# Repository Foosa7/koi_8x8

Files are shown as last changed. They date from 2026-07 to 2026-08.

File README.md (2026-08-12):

# Koi 8×8 — 64-channel current-source driver / readout

An open-hardware, low-cost controller for driving **TiN thermo-optic heaters on
photonic chips**: 64 independent precision current sources with per-channel
voltage readback, built from one controller board and eight hot-pluggable
8-channel analog boards.

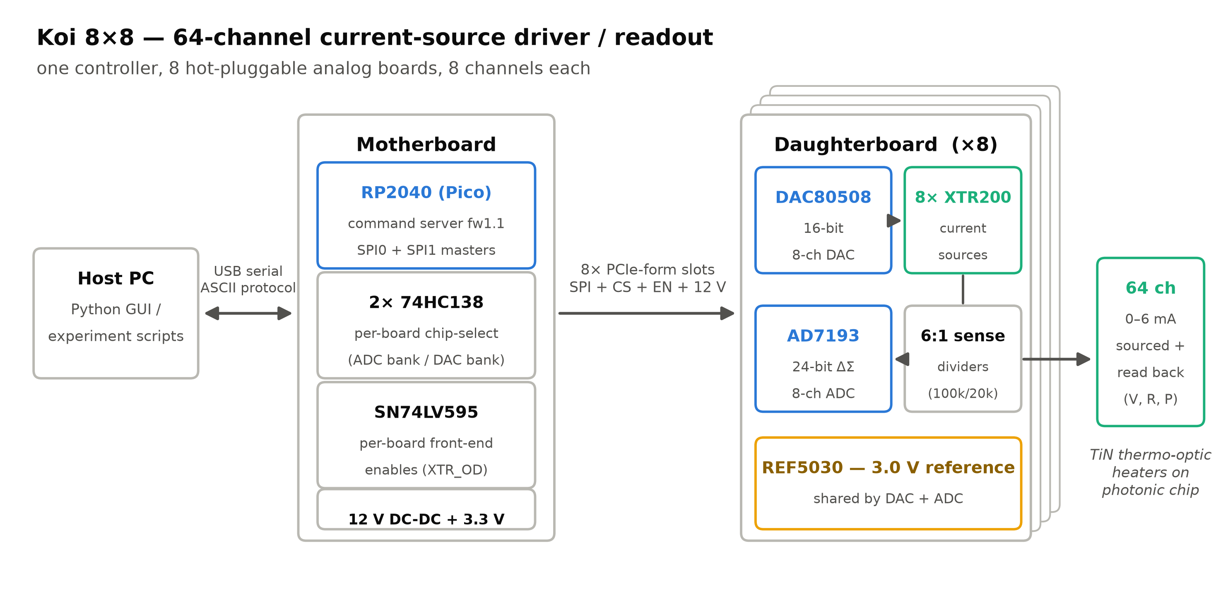
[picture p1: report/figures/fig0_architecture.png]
System architecture


Each daughterboard pairs a 16-bit DAC (DAC80508) with eight XTR200 precision
current sources, and reads the voltage across each load through a 6:1 divider
with a 24-bit ΔΣ ADC (AD7193), so the host gets current, voltage, resistance,
and power per channel. A Raspberry Pi Pico (RP2040) on the motherboard runs a
line-based ASCII command server over USB — one `ISETA` sets all 64 currents,
one `MEASA?` reads all 64 voltages.

## The boards

| [Motherboard](hardware/motherboard/) — RP2040 controller, 8 slots | [Daughterboard](hardware/daughterboard/) — 8 analog channels, ×8 |
| --- | --- |
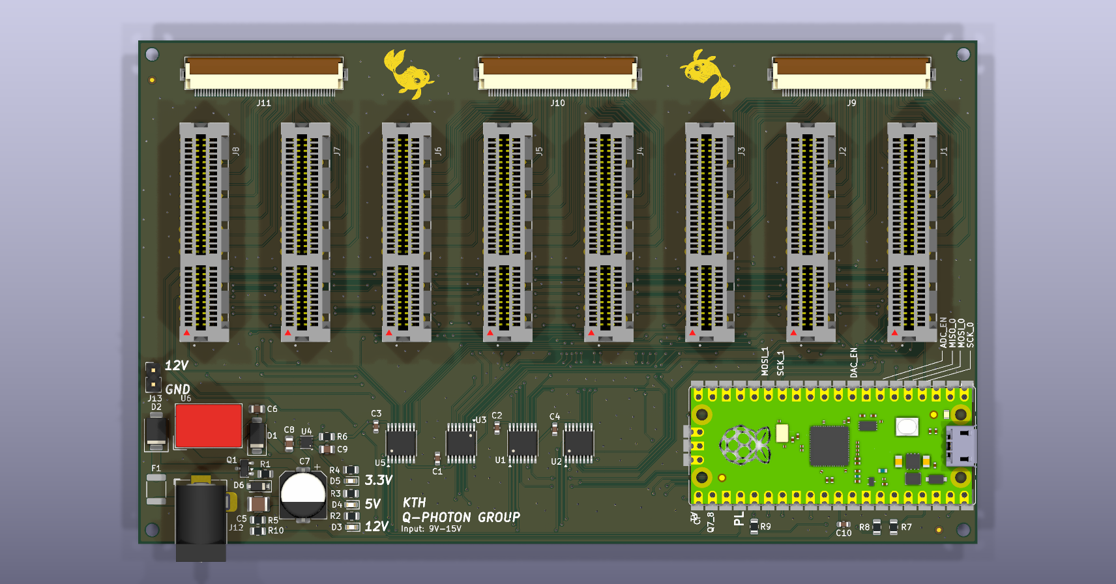
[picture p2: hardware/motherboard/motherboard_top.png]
Motherboard
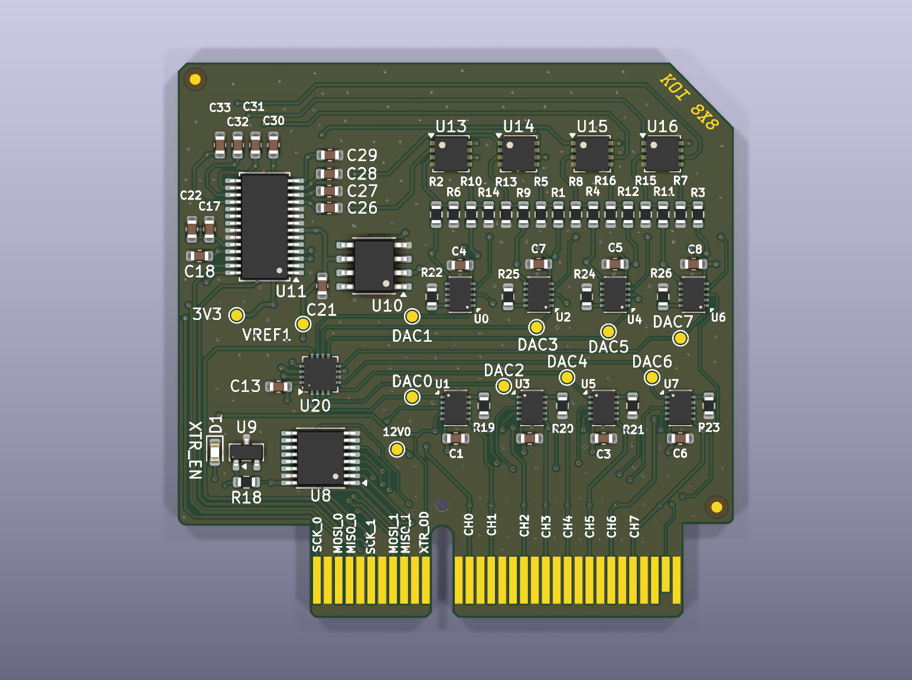
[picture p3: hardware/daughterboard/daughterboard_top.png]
Daughterboard
|  |  |

Renders are regenerated from the KiCad boards with `kicad-cli pcb render`; each
board's own README has top, bottom, and transparent-background views.

## Key numbers

| Metric | Value |
| --- | --- |
| Channels | 64 (8 boards × 8), hot-pluggable per board |
| Current range | 0–6 mA per channel (working range 0.25–6 mA), 16-bit setting |
| Readback | 24-bit ΔΣ, divider-corrected load voltage → V / R / P per channel |
| Linearity (measured, 23 ch) | worst-case ±0.32 µA deviation from linear over 0.25–6 mA (≈0.006 % of span) |
| Offset (pre-calibration) | ≈24 µA systematic, uniform across channels; single-point cal brings it to the ±4 µA XTR200 device floor (Keithley campaign planned) |
| Full 64-channel scan | ≈11 ms/channel at the default filter rate (~0.7 s for all 64; filter rate adjustable live) |
| Parts cost | **$709 per system ≈ $11.08/channel** ([master_bom.csv](master_bom.csv)) — commercial equivalents (e.g. Qontrol) ≈ $125/channel |

## Measured results (3 boards / 24 channels, 2026-07-03)

| | |
| --- | --- |
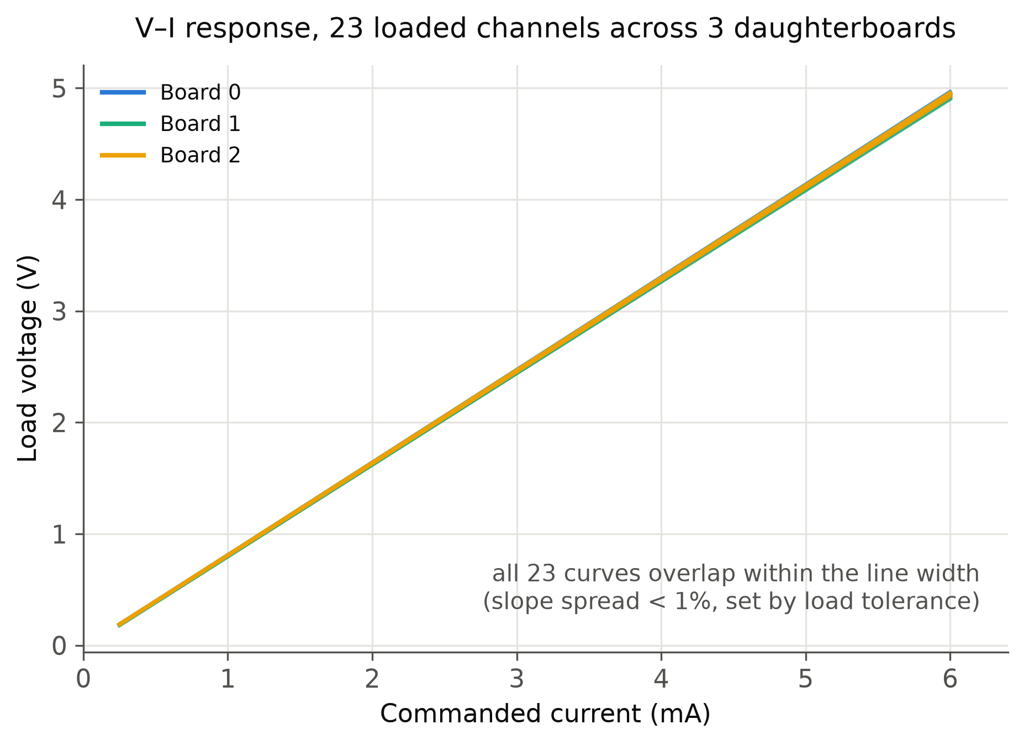
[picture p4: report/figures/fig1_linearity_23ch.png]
V-I linearity
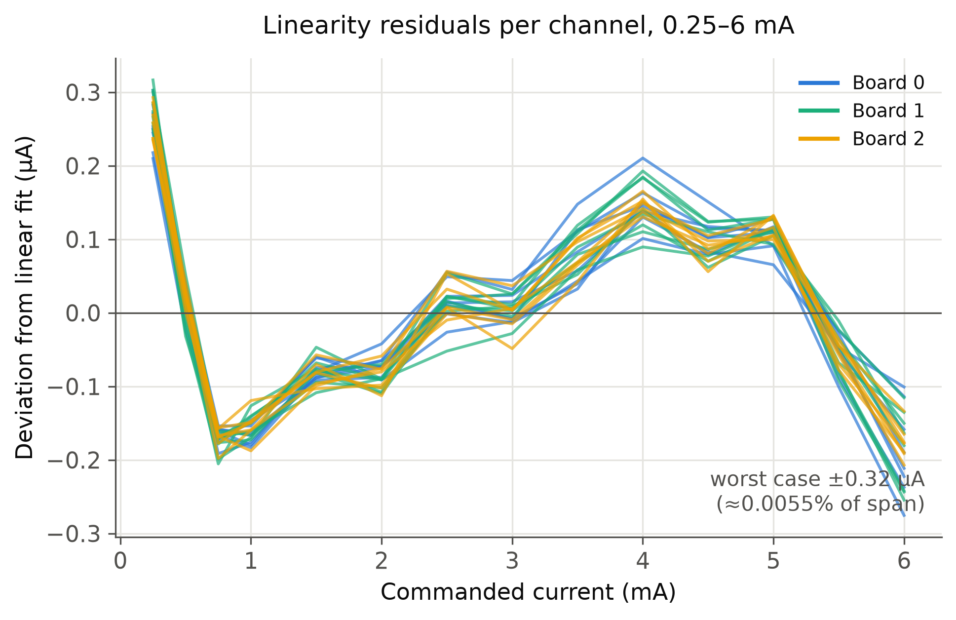
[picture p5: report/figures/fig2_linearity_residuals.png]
Residuals
|  |  |

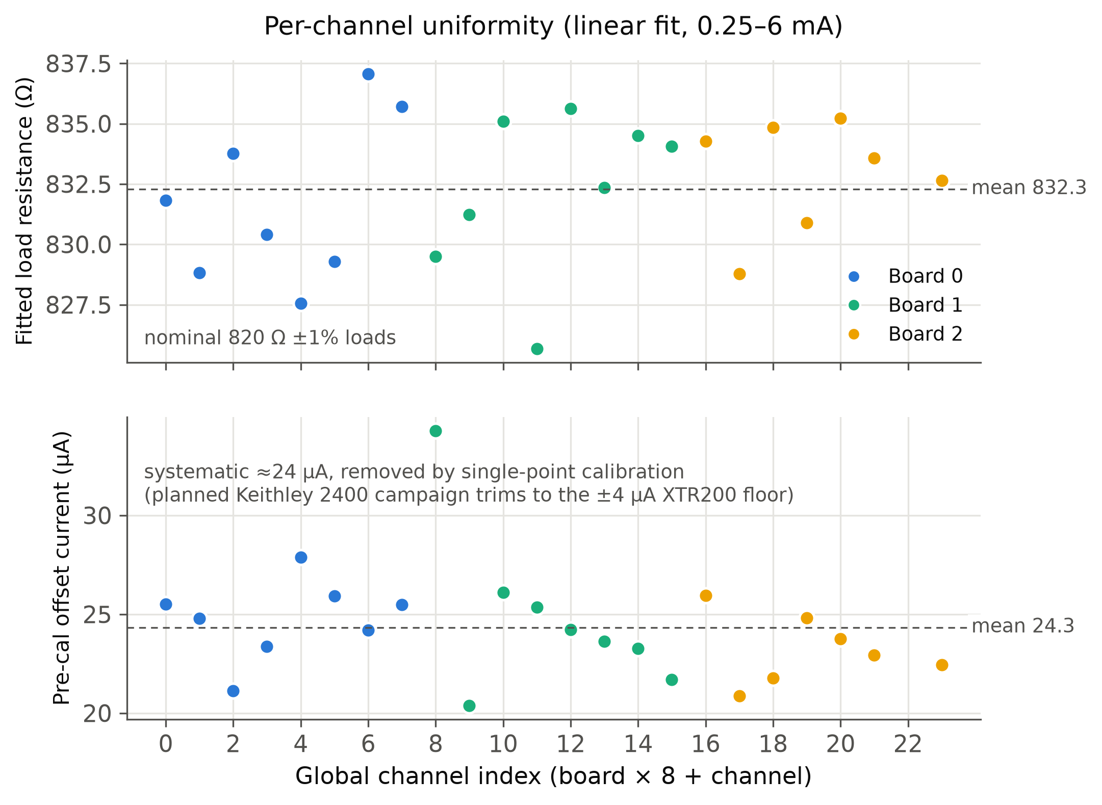
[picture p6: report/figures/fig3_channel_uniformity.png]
Per-channel uniformity


Three populated daughterboards were swept 0.1–6 mA into nominal 820 Ω ±1 %
loads (one channel had no load fitted during the run and is excluded). All 23
loaded channels are linear to within ±0.32 µA and show a uniform ~24 µA
pre-calibration offset — a systematic that the planned per-channel calibration
removes. Figures are regenerated from the raw bench CSVs by
`report/figures/make_figures.py`.

## What's in this folder

| Path | Contents |
| --- | --- |
| `report/figures/` | Architecture diagram + measurement figures (and the scripts that generate them) |
| `hardware/motherboard/` | KiCad project, schematic PDF (`Schematics/`), power-tree spec (`POWER.md`), top/bottom/transparent renders, fab outputs (`production/`: gerbers, BOM, positions) |
| `hardware/daughterboard/` | Same set for the analog board, plus an interactive HTML BOM (`bom/ibom.html`) |
| `hardware/render/` | Headless KiCad → pcb2blender → Cycles pipeline for photorealistic board renders |
| `master_bom.csv` | Consolidated system BOM with unit prices and cost total |
| `firmware/motherboard-test/` | RP2040 firmware (PlatformIO, `pio run -t upload`) and Python host tools — `tools/koi_gui.py` is a live 8×8 monitor GUI; `tools/*.csv` are the raw bench datasets |
| `paper/main.pdf` | Draft HardwareX manuscript (validation section pending the calibration campaign) |

## Status (August 2026)

**In fab:** both revised boards were released to fabrication on **2026-08-12**.
The motherboard adds the protected input stage (PPTC + SMBJ16A TVS + P-FET
reverse-polarity with a BZT52C18 gate clamp), the 12 → 5 → 3.3 V tree with the
`3V3_EN` interlock, a +12 V sense divider into `GPIO26`, and the `U3.~OE`
cutover to `GPIO19`; the daughterboard adds the OPA2333 followers (U13–U16) and
their 1 kΩ series resistors. `hardware/*/production/` holds the exact gerber /
BOM / position sets that were sent.

**Done:** rev-1 hardware designed, fabricated, and brought up; firmware 1.1
with robust host protocol (auto-detection, hot-rescan, fast scanning); host GUI
and calibration tooling; all 8 daughterboards populated and tested (initial
3-board/24-channel results above — production sign-off).

**Resolved:** the ~3 mV offset seen during the 8-board test was the AD7193's
*internal* input buffer. With the 6:1 divider, a low-current channel's ADC input
sits below the buffered mode's usable common-mode range, so the buffer added a
systematic offset rather than tracking. Fixed by disabling it (`CONF.BUF = 0`)
and adding 8 external unity-gain **OPA2333** followers (U13–U16) between the
divider taps and the ADC inputs.

**Next:** Keithley 2400/2100 per-channel calibration campaign (jig designed,
parts list ready); HardwareX submission.

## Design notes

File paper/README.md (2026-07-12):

# Koi 8×8 — HardwareX manuscript

Draft of the HardwareX paper for the 64-channel current-source driver / readout controller.

## Build
```bash
make            # -> main.pdf  (runs pdflatex twice)
make clean      # remove aux files
```
Requires `pdflatex` (TeX Live). No bibliography is wired up yet (`refs.bib` is empty).

## Status / how to work in it
- `main.tex` is the manuscript. It follows the HardwareX section order
  (Specifications table → Hardware in context → Description → Design files →
  BOM → Build → Operation → Validation → Capabilities → Declarations).
- Search `main.tex` for `\todo{...}` (rendered in red in the PDF) — each marks
  text or data still to add. The biggest block is **Section 8, Validation** —
  that's the Keithley calibration campaign output.
- Set `\draftfalse` (comment the `\drafttrue` line near the top) to hide the
  TODO/notes markers for a clean read-through.
- For final submission, port into the official HardwareX `els-cas-templates`
  (elsarticle) template; this article-class version is for drafting.

## Where the seeded content came from
Architecture prose, the host-command protocol table, the measurement model, and
preliminary bench numbers are transcribed from the project `CLAUDE.md`. The
calibration tables and all quantitative validation figures are pending the
Keithley 2400 campaign.

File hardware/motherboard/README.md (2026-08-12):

# Motherboard — RP2040 controller board

The controller board for Koi 8×8. Carries a Raspberry Pi Pico (RP2040) and
hosts up to 8 [daughterboards](../daughterboard/) in PCIe-x4 card-edge slots,
addressing each board's DAC/ADC over a shared SPI bus. Formerly codenamed
`MOBO`. The PC talks to the Pico's firmware over USB serial — see
[`firmware/motherboard-test/`](../../firmware/motherboard-test/).

| Top | Bottom |
| --- | --- |
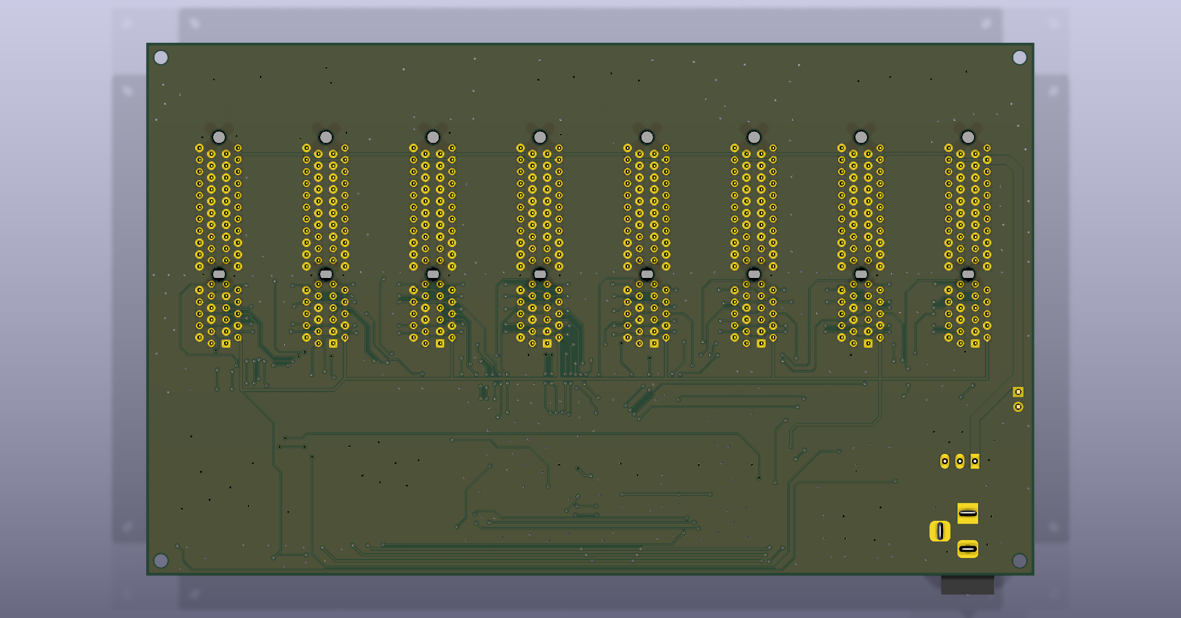
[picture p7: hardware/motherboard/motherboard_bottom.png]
Motherboard bottom
| Motherboard top |  |

Motherboard 3D render

Same top view with an alpha background, for dropping onto slides or into the
paper's figures:

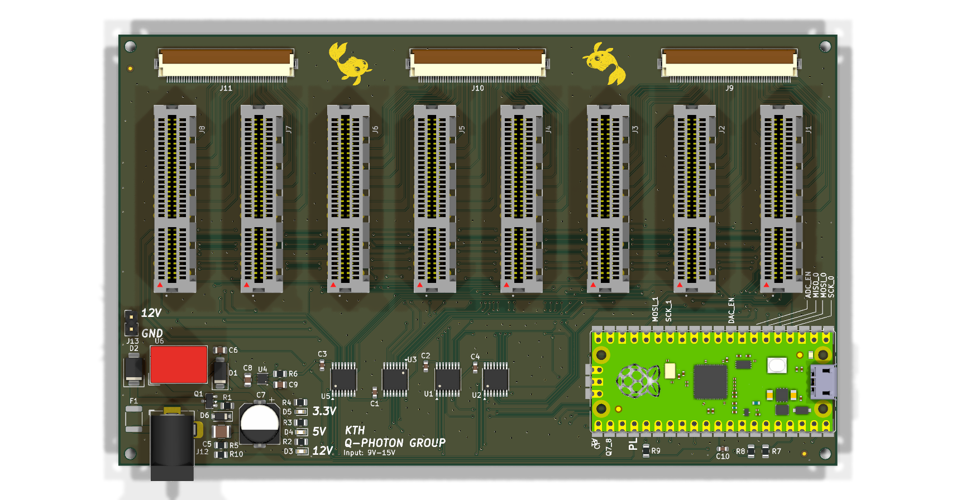
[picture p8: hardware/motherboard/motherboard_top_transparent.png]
Motherboard top, transparent background


## What's on it

| Ref | Part | Function |
| --- | --- | --- |
| A1 | Raspberry Pi Pico (RP2040) | Runs the firmware; USB-serial host link |
| U1, U5 | SN74LV138 (74HC138) | 3-to-8 decoders — ADC/DAC chip-select across the 8 slots |
| U3 | SN74LV595 | Shift register — XTR200 front-end enables |
| U2 | TMUX1208PW | 8:1 analog mux |
| J1–J8 | Samtec PCIE-064-02-F-D-TH | 8 daughterboard slots (PCIe-x4 sockets) |
| J9–J11 | Molex 54132-5033 | 50-pin FFC connectors — channel outputs |

### Power tree

The barrel jack is the only power source; the Pico is a peripheral that cannot
run without it, enforced in hardware by the `3V3_EN` interlock (R7/R8) rather
than in firmware. Full design rationale: [`POWER.md`](POWER.md).

| Ref | Part | Function |
| --- | --- | --- |
| J12 | Barrel jack + switch pin | DC power in, 9–15 V |
| F1 | 1812L150/24MR polyfuse | Input overcurrent protection |
| D2 | SMBJ16A | Input TVS clamp (26 V clamping voltage) |
| Q1 | AO3407A | P-FET reverse-polarity protection |
| D6 | BZT52C18 | `Q1` gate–source clamp |
| U6 | K7805-500R3 | 5 V switching regulator |
| U4 | LP5912-3.3DRV | 3.3 V LDO — logic rail and daughterboard `+3V3` |
| D1 | SS34 | Feeds the Pico's VSYS from the board's 5 V rail |
| R7, R8 | 10 kΩ / 4.7 kΩ | `3V3_EN` interlock divider |
| R5, R10, C10 | 100 kΩ / 22 kΩ / 100 nF | +12 V sense divider into `GPIO26`/ADC0 (×5.5455) |

Full pricing and part numbers: [`../../master_bom.csv`](../../master_bom.csv).

## Files

| File | What it is |
| --- | --- |
| `motherboard.kicad_pro` / `.kicad_sch` / `.kicad_pcb` | The KiCad project |
| `Schematics/motherboard.pdf` | Exported schematic |
| `production/` | Fab outputs — gerbers, BOM, positions, netlist |
| `POWER.md` | Power-tree design spec — input protection chain and the `3V3_EN` interlock |
| `motherboard*.png` | Board views above, regenerated with `kicad-cli pcb render` |
| `PCIE-064-02-F-D-TH.stp`, `Pico.wrl` | 3D models used for the renders above |

Photorealistic Cycles renders (`motherboard_render*.png`) are produced by the
pipeline in [`../render/`](../render/) — not generated yet.

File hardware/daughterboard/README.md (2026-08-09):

# Daughterboard — 8-channel analog board

The analog front-end board for Koi 8×8. Eight of these plug into one
[motherboard](../motherboard/) over a PCIe-x4 card-edge connector, giving the
system 8 boards × 8 channels = 64 independent current sources with voltage
readback. Formerly codenamed `OuttaQontrol`/`OuttaControl`.

| Top | Bottom |
| --- | --- |
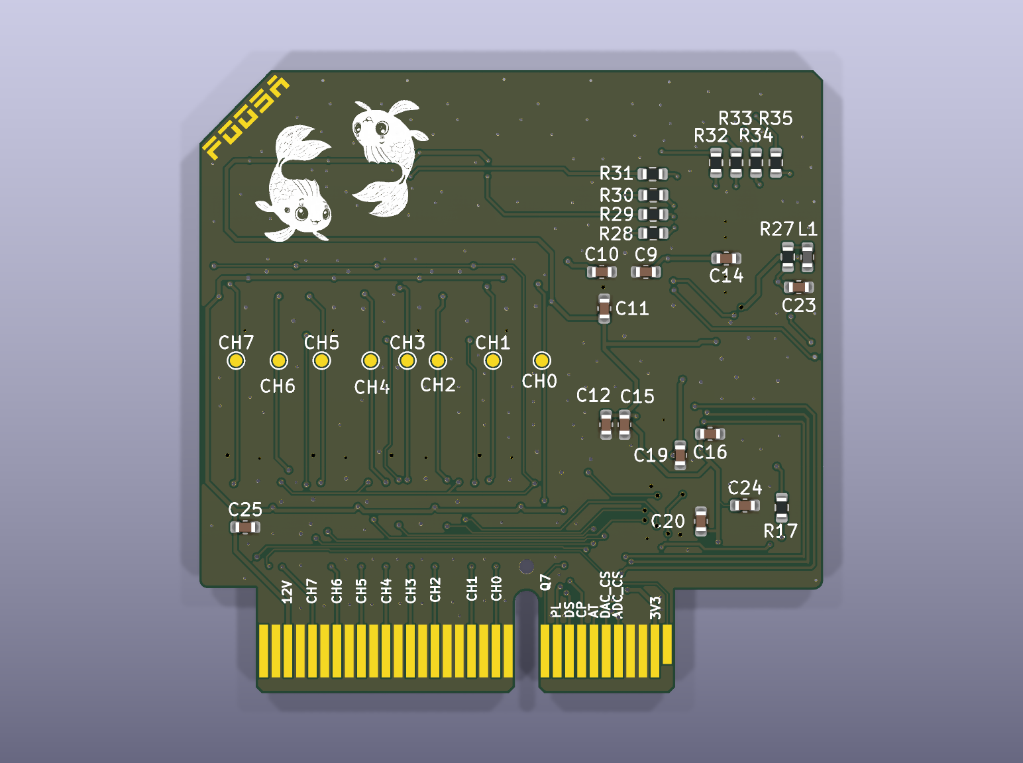
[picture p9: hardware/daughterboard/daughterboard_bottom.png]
Daughterboard bottom
| Daughterboard top |  |

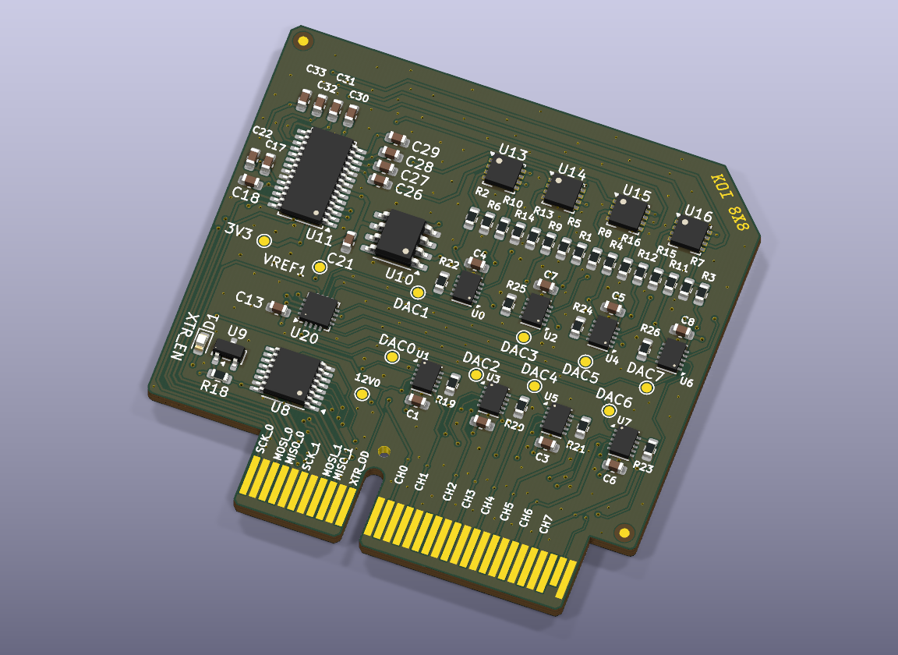
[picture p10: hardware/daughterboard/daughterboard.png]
Daughterboard 3D render


Same top view with an alpha background, for dropping onto slides or into the
paper's figures:

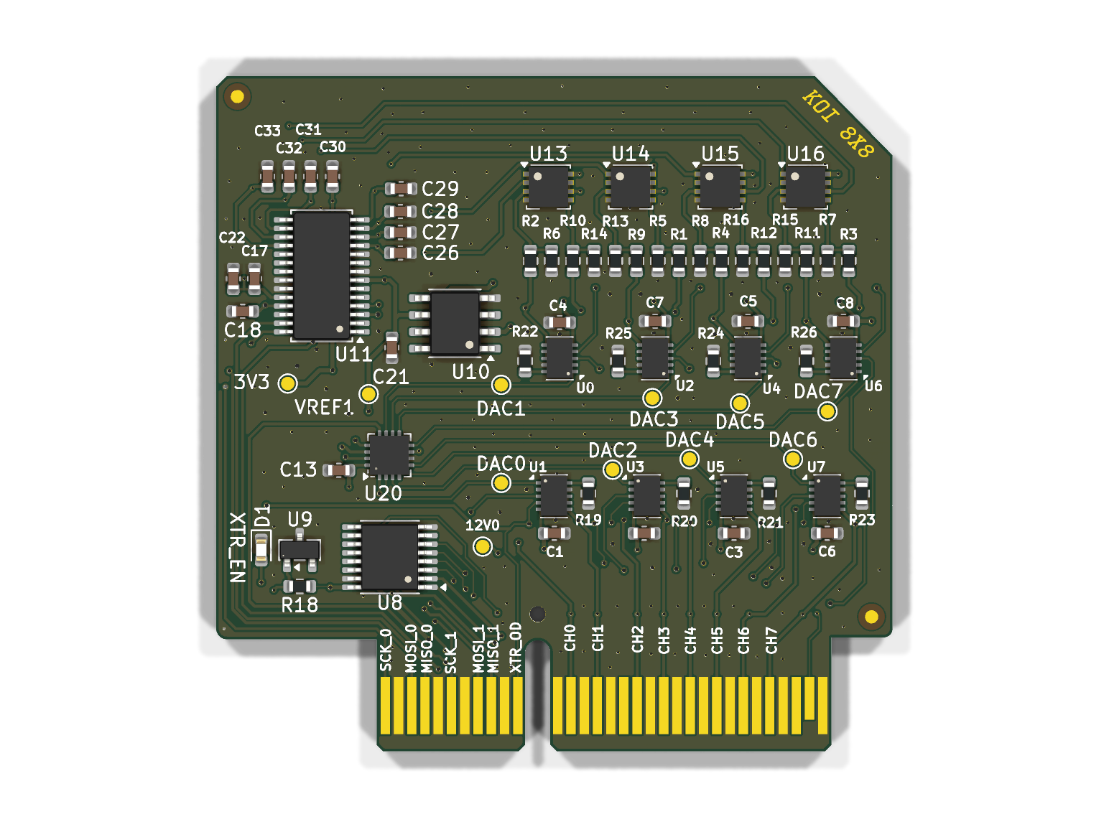
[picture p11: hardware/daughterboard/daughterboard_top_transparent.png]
Daughterboard top, transparent background


## What's on it

| Ref | Part | Function |
| --- | --- | --- |
| U0–U7 | XTR200 (WSON-10) | Precision current-source front end, one per channel |
| U20 | DAC80508Z (WQFN-16) | 16-bit, 8-channel DAC — sets the 8 channel currents |
| U11 | AD7193 (TSSOP-28) | 24-bit ΔΣ ADC — reads back the 8 channel voltages |
| U10 | REF5030 (SOIC-8) | 3.0 V precision reference, shared by the DAC and ADC on this board |
| U8 | SN74LV165A (TSSOP-16) | Parallel-load 8-bit shift register |
| U9 | AT21CS01 | 1-Wire EEPROM (board ID/config) — new in this revision |
| R19–R26 | 4.7 kΩ 0.1 % | Per-channel sense resistors |
| R1–R4, R9–R12, R17 / R5–R8, R13–R16 | 100 kΩ / 20 kΩ 0.1 % | 6:1 sense divider (top/bottom) — firmware reads the raw ADC-pin voltage and the host applies ×6 to get true heater voltage |
| J1 | Custom PCIe-x4 card-edge | Connector into the motherboard slot |

Full pricing and part numbers: [`../../master_bom.csv`](../../master_bom.csv).

## Files

| File | What it is |
| --- | --- |
| `daughterboard.kicad_pro` / `.kicad_sch` / `.kicad_pcb` | The KiCad project (current revision) |
| `Schematics/daughterboard.pdf` | Exported schematic |
| `bom/ibom.html` | Interactive HTML BOM (open in a browser) |
| `production/` | Fab outputs — gerbers, BOM, positions, netlist |
| `daughterboard*.png` | Board views above, regenerated with `kicad-cli pcb render` |
| `version 1/` | The prior board revision (pre-EEPROM), kept for reference, incl. its own PDN sim results |
| `padne_out_v3/`, `results_v3/` | Power-delivery-network (PDN) simulation outputs for this revision — current-density and IR-drop maps |

Photorealistic Cycles renders (`daughterboard_render*.png`) are produced by the
pipeline in [`../render/`](../render/) — not generated yet.

See **[`CLAUDE.md`](CLAUDE.md)** for the full development-facing breakdown of
these files, the netlist/revision history, and the padne PDN simulation
workflow in detail.

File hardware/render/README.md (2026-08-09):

# Photorealistic board renders

Cycles renders of the two KiCad boards, via
[pcb2blender](https://github.com/30350n/pcb2blender) (GPL-3.0, by 30350n). The
`.pcb3d` intermediate carries the real soldermask/silkscreen/copper artwork as
texture maps plus the component meshes, so the output is a lit 3D scene rather
than KiCad's viewport screenshot.

These are **separate files** from the `kicad-cli`-generated `*_top.png` /
`*_bottom.png` / `*.png` next to each project — those stay as the quick
reference views. Blender output is named `*_render*.png`.

## One-time setup

The upstream release is pinned to KiCad 9.0 / Blender 5.1; both need nudging.

1. **Blender add-on.** Download `pcb2blender_importer_v2-17-5_b5-1.zip` from the
   [v2.17.5 release](https://github.com/30350n/pcb2blender/releases/tag/v2.17.5-k9.0-b5.1).
   Blender 5.2 is excluded by the manifest's `blender_version_max`, so raise it
   before installing:

   ```bash
   unzip -q pcb2blender_importer_v2-17-5_b5-1.zip -d imp && \
   sed -i 's/^blender_version_max = "5.2.0"/blender_version_max = "5.3.0"/' imp/blender_manifest.toml && \
   (cd imp && zip -qr ../importer_patched.zip .) && \
   blender --command extension install-file -r user_default --enable importer_patched.zip
   ```

2. **Exporter.** Already vendored here as `pcb2blender_exporter/` (`export.py` +
   `pcb3d.py`, unmodified, from `pcb2blender_exporter_v2-17-5_k9-0.zip`). It is
   normally a pcbnew action plugin; `export_pcb3d.py` drives it headless instead.

## Running

```bash
./hardware/render/render.sh              # both boards, all four views
./hardware/render/render.sh mother       # one board
SAMPLES=320 ./hardware/render/render.sh  # slower, cleaner
```

Roughly 8 min per view at 1568×1176 / 160 samples on 12 CPU cores.

## Files

| File | What it does |
| --- | --- |
| `export_pcb3d.py` | `.kicad_pcb` → `.pcb3d`, headless. Patches `pcbnew.GetBoard()` and routes VRML export through `kicad-cli`. |
| `render_pcb.py` | Blender script: import `.pcb3d`, build a studio rig, render. `--view iso\|top\|bottom`, `--transparent`, `--samples`, `--exposure`. |
| `render.sh` | Both boards × four views at the sizes the READMEs expect. |
| `pcb2blender_exporter/` | Vendored upstream exporter (GPL-3.0). |

## KiCad 10 notes

- `pcbnew.ExportVRML()` returns `False` outside the pcbnew GUI, so
  `export_pcb3d.py` shells out to `kicad-cli pcb export vrml` instead. That call
  **must** pass `--user-origin 0x0mm`: the plugin emits pad coordinates in
  absolute page mm, and kicad-cli otherwise centres the mesh on its own origin,
  scattering every solder joint ~100 mm off the board.
- `unknown drill shape '2'` during export is harmless — KiCad 10 added
  `PAD_DRILL_SHAPE_UNDEFINED`, which the pinned exporter's enum doesn't list. It
  degrades to `UNKNOWN` and only affects solder-joint geometry on pads with no
  drill.
- Cycles' device enumeration walks *every* GPU backend, and the oneAPI
  level-zero loader segfaults Blender on this machine, so renders default to
  CPU. `--gpu` opts back in if that gets fixed.

## Surface finish

Both boards carry `copper_finish "None"` in their KiCad stackup, which would
render the PCIe edge fingers as bare copper. `render.sh` passes `--finish ENIG`
to override that. Fix the stackup in KiCad and the override can go.

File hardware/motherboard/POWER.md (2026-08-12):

# Motherboard power tree — design spec

Protected barrel-jack entry, 5 V buck, 3.3 V LDO, and a hardware interlock that makes the Pico a
subsystem of the board rather than an independent peer.

**Status: released to fabrication 2026-08-12.** The tree, the protection chain and the interlock
are on the board as of `397a4a4`; "What exists today" lists what is still outstanding. Input range
for this revision is **9–15 V**. Changes are no longer free — this revision is at the fab, so
anything below now describes a future spin.

Make changes **in KiCad**, not by editing `motherboard.kicad_sch` by hand.

## Architectural rule

**The barrel jack is the only power source, and the Pico cannot run without it.**

The Pico is a communications peripheral. It never sources power into the board, the board never
back-powers it, and — the part that makes everything else simple — the two can never be in
different power states. That last property is enforced in hardware by the `3V3_EN` interlock
below, not in firmware.

## What exists today

**Built as of `397a4a4` (2026-08-10).** The rework in this document has landed: the protection
chain, the two-stage tree and the interlock are all in the schematic and on the board. All three
defects this section used to list are fixed.

```
J12 ──► VIN_JACK ──► F1 (1812L150/24MR) ──┬──► D2 (TVS) ──► GND
                                          └──► Q1 (AO3407A) drain
                            Q1 source ──► +12V ──┬──► J1–J8 pin A30, J13
                                                 ├──► C5 10µ, C7 220µ/35 V
                                                 └──► U6 (K7805-500R3) Vin
                                 U6 Vout ──► +5V ──┬──► D1 (SS34) ──► VSYS (A1 pin 39)
                                                   ├──► U4 (LP5912-3.3) IN + EN
                                                   └──► C6 22µ, C8 10µ
                                 U4 OUT ──► +3.3V ──► U1/U2/U3/U5, J1–J8 pin A2, C1–C4 100n, C9 10µ
                                 U4 PG  ──► R6 100k ──► +3.3V, and A1 pin 11 (GPIO8)
      3V3_EN (A1 pin 37) ──┬── R7 10k ── GND
                           └── R8 4.7k ── +3.3V (U4 pin 1)
      +12V ──► R5 100k ──┬── 12V_SENSE ──► A1 pin 31 (GPIO26/ADC0)
                         ├── R10 22k ── GND
                         └── C10 100n ── GND (at the Pico pin)
      A1 pin 36 (3V3) and pin 40 (VBUS): unconnected.
      R1 100k: Q1 gate → GND.   D6: Q1 gate–source clamp.   R9 10k: U3 `~OE` pull-up.
      D3/D4/D5 + R2/R3/R4: rail LEDs on +12 V / +5 V / +3.3 V.
```

**Input range for this revision is 9–15 V**, set at the jack. This is wider than the 12 V nominal
the first draft assumed, and it drives the D2 and D6 selections below. Note the jack voltage *is*
the +12 V rail — it reaches `J1..J8.A30` and thence `VSP` (pin 5) of all 64 XTR200s — so it is not
a free input range: raising it raises XTR200 pass dissipation proportionally.

### Refdes drift — read this before cross-referencing

The build tables further down were written against the pre-rework schematic and use refdes that
the board assigns differently. Current mapping:

| This document originally said | On the board | Role |
| --- | --- | --- |
| `U8` | **`U6`** | K7805-500R3 buck |
| `R3` | **`R1`** | Q1 gate → GND, 100 kΩ |
| `D3` (optional gate zener) | **`D6`** | Q1 gate–source clamp — now placed, and now required |
| `C8` | **`C5`** | K7805 input, 10 µF 1210 |
| `C9` | **`C6`** | K7805 output, 22 µF 0805 |
| `C10` | **`C8`** | LDO input, 10 µF 0805 |
| `C11` | **`C9`** | LDO output, 10 µF 0805 |

`R2`/`R3`/`R4` and `D3`/`D4`/`D5` are the **rail LEDs** on the board, so the "Still to add" table's
use of `R4`, `R5` and `D4` for the sense divider and clamp is a collision.

`R5`, `R10` and `C10` are now the sense divider and its filter — note the bottom leg is **`R10`**,
not the `R13` earlier drafts of this document specced. Free refdes are `R11`+, `C11`+, `D7`+.

### Still outstanding

Verified against a fresh netlist export and the `.kicad_pcb` on **2026-08-11**. Schematic and
PCB agree on every net; no pad is left unreached by its own net's copper.

| Item | Where |
| --- | --- |
| `Q1` is drawn with the `AO3401A` symbol while valued `AO3407A` | "Schematic hygiene" |
| `D2`'s symbol carries no polarity (pins `A1`/`A2`) | "Schematic hygiene" |

**Electrically the board is complete.** Both open items are drawing hygiene, not connectivity.

Closed since the last revision of this document: the +12 V sense divider (`R5`/`R10`/`C10` →
`GPIO26`), the `U3.~OE` cutover to `GPIO19`, `D2` → `SMBJ16A`, `D6` → `BZT52C18`, the
`#PWR050`/`#PWR036` symbol swap, and `J1..J8.B31` → GND on all eight with the dangling one-node
`PRSNT` net deleted.

Decided against, deliberately — see "Board-side defaults" and "Decoupling": the `ADC_EN`/`DAC_EN`
pull-ups, the `U2` `EN` pull-down, and the 10 µF at the +3.3 V connector bank.

✅ **`production/` was regenerated 2026-08-11 20:27** from the current board — it now includes the
sense divider, the `~OE` cutover, the `D2`/`D6` changes and `J8.B31`. **This is the revision sent
to fabrication (2026-08-12).**

⚠️ **`motherboard.net` is still the 2026-08-10 18:04 export** and predates those changes. Re-export
from KiCad before using it to check connectivity; `production/netlist.ipc` is the current one.

✅ **DRC run 2026-08-12** (`kicad-cli pcb drc motherboard.kicad_pcb` — the CLI *can* open this board
now that KiCad 10.0.5 has re-saved it; only older on-disk formats defeated it). **0 errors, 0
unconnected pads**, 4 warnings, none of them manufacturing defects:

| Warning | What it is |
| --- | --- |
| `silk_overlap` ×1 | `CP` text vs `A1`'s reference designator |
| `silk_edge_clearance` ×2 | `J12` silkscreen clipped by the board edge |
| `lib_footprint_mismatch` ×1 | `U3`'s TSSOP-16 differs from `Package_SO`'s copy (local override) |

## Why this topology

The 5 V rail pre-regulates for the LDO and feeds VSYS. Dropping 12 V → 3.3 V linearly would
burn 8.7 V × 110 mA ≈ **0.96 W**; the switching stage cuts that to ~0.19 W. Switcher-then-LDO
also keeps switching noise off the rail feeding AD7193 AVDD.

The board previously carried an L7805 here, which threw that saving away: 7 V × 210 mA ≈ **1.5 W**
in TO-220F with no heatsink (θJA ≈ 60 °C/W) is a ~90 °C rise. The K7805-500R3's pinout is
deliberately LM78xx-compatible, so the swap cost **no net changes** — symbol, value and footprint
only. At 15 V in the linear option would have been worse still (9.7 V × 210 mA ≈ 2.0 W).

## The 3V3_EN interlock

`3V3_EN` is the RT6150's enable, pulled up to VSYS through 100 kΩ on the Pico module. Two
resistors turn "the Pico must not run without board power" into a hardware fact:

| Ref | Value | Connection |
| --- | --- | --- |
| `R7` | **10 kΩ** | 3V3_EN → GND |
| `R8` | **4.7 kΩ** | board +3.3 V (U4 pin 1) → 3V3_EN |

✅ **Built and verified against the netlist.** Both resistors carry these values and `R8` returns
to the board rail. **The 10 kΩ is what makes it work:** it has to be small against the module's
internal 100 kΩ pull-up to VSYS. A 100 kΩ/100 kΩ pair — what the board carried before the
rework — leaves 3V3_EN at ~1.6 V with the board rail dead, which the RT6150 reads as "enabled".

✅ **Thresholds verified (RT6150A/B datasheet DS6150A/B-06, July 2018).** EN input voltage:
**logic-high min 1.2 V, logic-low max 0.4 V**, input current 0.01 µA typ / 1 µA max. The Raspberry
Pi documentation confirms 3V3_EN is pulled to VSYS through **100 kΩ** on the module.

| Condition | 3V3_EN | Result |
| --- | --- | --- |
| Board +3.3 V dead, VSYS = 4.7 V from USB | **0.146 V** | 0.25 V below the guaranteed-low threshold → off |
| Board +3.3 V up, VSYS = 4.7 V | **2.32 V** | 1.12 V above the guaranteed-high threshold → on |

Both are outside the indeterminate band. **The 10 kΩ is load-bearing** — it has to be small
against the internal 100 kΩ. At 100 k/100 k the "off" case lands at 1.57 V (enabled); even at
22 kΩ it reaches 0.6 V, inside the undefined region.

⚠️ **Where the 0.146 V comes from, because it matters.** An earlier version of this section
quoted **0.43 V** for the same case — 4.7 V × 10/110, i.e. the internal pull-up against `R7`
alone. That figure ignores `R8`, and it sits *above* the 0.4 V guaranteed-low threshold. The
0.146 V figure is the correct one and includes `R8` pulling into a dead +3.3 V rail
(10 k ‖ 4.7 k = 3.2 k). It is valid only because that rail really does sit near 0 V when
unpowered — `D5` + `R4` (680 Ω) to GND plus five CMOS loads hold it down. If the rail ever
floated instead, you would be back at 0.43 V and marginally out of spec. It doesn't, so the
design is sound as built; but do not "simplify" `R8` away or move it to a lighter rail.

### Why this closes every case

| Jack | USB | +12 V | +3.3 V | VSYS | RP2040 | Result |
| --- | --- | --- | --- | --- | --- | --- |
| ✅ | ✅ | up | up | from either source | running | Normal operation |
| ✅ | ❌ | up | up | from board 5 V via D1 | running | Board alive, Pico alive — no dead-Pico back-feed |
| ❌ | ✅ | — | — | 4.7 V from VBUS | **held off** | IOVDD never comes up; every GPIO genuinely unpowered and high-Z |
| ❌ | ❌ | — | — | — | off | Everything down |

The third row is the one that matters. With the regulator disabled, the RP2040's IOVDD is
unpowered, so its pins are high-Z in the real sense — not "firmware left them as inputs." There
is nothing to drive the board and nothing to gate in software.

**D1 is load-bearing for row two.** Feeding VSYS from the board's 5 V is what guarantees
jack-on ⇒ Pico-on. Without it, a jack-on/USB-off system would have powered daughterboards
driving MISO into a dead Pico — the interlock alone doesn't fix that direction.

### The cost

**You cannot flash the Pico over USB alone.** Firmware updates require the jack connected.
Defensible for an instrument — nothing else works without power either — but it's a real change
in how the board is serviced. Decide deliberately rather than discovering it during bring-up.

### Power-up ordering

+12 V rises first (straight from the jack), then 5 V, then 3.3 V, and the Pico enables last.

⚠️ **An earlier version of this section claimed that ordering was automatically safe on the
daughterboard side. It is not, and the reason is U3's `~OE` wiring.** The XTR200's `OD` pin is
active-**LOW**-enable (OD HIGH = disabled, the power-on default from its internal pullup; see
`firmware/motherboard-test/CLAUDE.md` § XTR595). But `U3.13` (`~OE`) is hardwired to **GND**, so
the '595 *actively drives* `XTR_OD_1..8` the moment +3.3 V comes up — the XTR200's internal
pullup never gets a say. `~SRCLR` (`U3.10`) is hardwired to **+3.3 V**, so nothing clears the
register either. Its power-on contents are indeterminate, and **any bit that comes up as 0
enables that whole daughterboard's front ends** for the ~100–200 ms before `xtr.begin()` runs.

Severity is limited by the DAC80508**Z**'s zero-scale power-on reset — the DACs sit at 0 V, so
the enabled channels are commanded to zero current rather than midscale. It is still a state the
board should not be able to reach.

**Fix:** pull `~OE` **up** to +3.3 V through 10 kΩ and drive it from a GPIO. Outputs stay Hi-Z
until firmware has shifted and latched a known 0xFF, and the XTR200 pullups hold OD high
throughout.

**Status: half done.** `R9` (10 kΩ, `C84376`) is placed next to U3 in the schematic, but
`U3.13` is still tied to GND — the pull-up cannot do anything until that connection is cut and
the pin routed to a GPIO. **Assigned pin: `GPIO19` (A1 pad 25).** With PRSNT dropped (below) the
GPIO cost is no longer a problem.

Firmware follow-up in `firmware/motherboard-test/`: hold `GPIO19` high — or simply leave it an
input and let `R9` do the work — until after the first `0xFF` shift and latch, then drive it low.

This also neutralises the other floating-input concern in the same window. `SCK_0`, `MOSI_0` and
`XTR_RCLK` float during boot too and could clock garbage into the '595, but with `~OE` high the
outputs are Hi-Z regardless of the register contents, so no pull resistors are needed on the SPI
lines.

## Board-side defaults

Even with the interlock, the Pico takes ~100–200 ms to boot and configure its GPIOs after the
rails are up. During that window `ADC_EN` and `DAC_EN` — the '138s' active-low `~E0` inputs —
float.

| Signal | Pull | Status |
| --- | --- | --- |
| `ADC_EN`, `DAC_EN` | 10 kΩ up to +3.3 V | ⛔ **Decided against (2026-08-11).** Not fitted. |

⚠️ **An earlier version of this section called a floating enable "harmful" because it can assert
a chip select into powered daughterboards. That overstates it.** A chip select asserted with no
`SCK` activity does nothing — SPI slaves act only on clock edges, and the Pico isn't driving the
clock during the window in question either. No transaction can occur, so nothing is corrupted.

What remains is the ordinary objection to a floating CMOS input: `~E0` sitting near mid-rail
turns both input transistors partly on, raising supply current and risking oscillation, for
~100–200 ms per power cycle. The bench result — eight daughterboards, working — is real evidence
that this window is benign in practice.

So these are **not** required. ⛔ **Decision, 2026-08-11: skipped.** The bench result — eight
daughterboards, working — stands, and a ~100–200 ms window of elevated supply current per power
cycle is not worth the parts. `ADC_EN` is `A1.7` + `U1.4` and `DAC_EN` is `A1.9` + `U5.4`, both
with no pull, and that is the intended final state.

If a future spin ever revisits it: 10 kΩ or 100 kΩ to +3.3 V, either fine against the RP2040's
12 mA drive (100 kΩ is gentler — 33 µA vs 330 µA sunk when the Pico drives low).

Same class, lowest priority, and **also skipped**: `U2` (TMUX1208PW) has an **active-high** EN on
pin 2, driven only by `GPIO9`. A 10 kΩ pull-**down** to GND would default the EEPROM mux to
disconnected. Genuinely optional — a mux connection with nothing driving it does nothing.

## Rail sensing

Only **+12 V** needs sensing. The +3.3 V sense originally specced here is redundant: with the
`3V3_EN` interlock, if the Pico is executing code at all then +3.3 V is necessarily up.

✅ **Built and verified 2026-08-11.** The net is named `12V_SENSE` on the board.

| Leg | Ref | Value | LCSC | Node |
| --- | --- | --- | --- | --- |
| Top | `R5` | 100 kΩ 1% 0805 | `C96346` | `+12V` → `12V_SENSE` |
| Bottom | `R10` | 22 kΩ 1% 0805 | `C114565` | `12V_SENSE` → GND |
| Filter | `C10` | 100 nF 0603 | `C14663` | `12V_SENSE` → GND, at the pin |

Ratio 22/122 = **0.1803**, into `GPIO26` / ADC0 (A1 pad 31). *(`R9` was already taken by the `~OE`
pull-up, so the bottom leg is `R10`.)*

**`C10` belongs at the Pico, not at the divider — and it is there:** 4.4 mm from `A1` pad 31,
on the same vertical trace. The tap runs ~110 mm from the divider at the power stage to the
Pico, at an 18.03 kΩ Thévenin impedance, so the filter earns its place at the load end. The
corridor it shares carries `A3`, `PL` and `Q7_8` — no SPI clock, and `A3` is static during a
transfer, so the coupling is benign.

Across the 9–15 V input range:

| Jack | ADC pin |
| --- | --- |
| 9 V | 1.623 V |
| 12 V | 2.164 V |
| 15 V | **2.705 V** |
| 18.3 V | 3.300 V — the fault ceiling |

Firmware conversion: `V12 = adc_volts * 5.5455` (122/22).

**No Schottky clamp.** Earlier drafts specced a BAT54S to the Pico's 3V3. Drop it: the 100 kΩ
top leg limits current into the pin's own ESD clamp to (26 − 3.6)/100 k ≈ 224 µA even during a
full TVS event, and the 100 nF slews the edge. **`C10` is load-bearing for that argument** —
half the justification for omitting the clamp is the cap, so do not delete it as "just a filter". The external diode adds a part and a net for
nothing. It would also have had nowhere good to clamp *to* — `A1` pin 36 must stay unconnected
(see "Rejected alternatives"), so the only available node is the board's own +3.3 V rail.

**No buffer either.** The 18.03 kΩ Thévenin looks high for an ADC input, but nothing here needs
an op-amp. Settling is not the issue — R_th × C_sample is ~100 ns, well inside the RP2040's
sample aperture. The switched-cap input's average draw is C_s·V·f_s, and *you choose f_s*: at a
monitoring rate of ~1 kSPS it is sub-µV across 18 kΩ. Take short bursts and idle; do not
free-run the ADC on this channel at hundreds of kSPS, which is the only way to make the
impedance matter. And a buffer would add offset to a measurement whose error is already
dominated by `ADC_VREF` (below), improving nothing measurable.

*(Contrast the daughterboard, where the AD7193 does need external OPA2333 followers behind an
almost identical 16.7 kΩ divider — a ΣΔ modulator samples continuously at a rate you cannot
lower, into a µV error budget, and both of its internal buffer modes are ruled out. See
`hardware/daughterboard/CLAUDE.md`.)*

**Accuracy is not a design goal here.** `ADC_VREF` (A1 pad 35) stays unconnected; the module
derives it from its own 3V3, so absolute accuracy is roughly ±4 % once the Pico's rail tolerance
and 1 % resistors are combined — ±600 mV on a 15 V rail. That is entirely adequate for "is the
adapter sagging", which is the whole purpose. Do not build a calibration on it. Quantisation is
irrelevant by comparison (~4.5 mV of rail per LSB), which is also why the divider was left at
100 k/22 k rather than rescaled to use more of the ADC span.

What firmware should do with it:

- Report the rail in the identify/status response.
- Refuse `ISET`/enable commands when +12 V is out of range, with a distinct error.
- Flag a sagging +12 V under full 64-channel load. At ~640 mA an undersized adapter will droop,
  and without rail sensing that surfaces as an unexplained *accuracy* problem rather than an
  obvious power problem.

## PRSNT — daughterboard seating detection

> ⛔ **Deferred — not implemented in this revision.** The decision is to tie `B31` to GND on all
> eight sockets and not use the feature. The rest of this section is kept because the reasoning is
> sound and the daughterboards already carry the loop, so it can be picked up in a later spin at
> no cost to them.
>
> **What to do on the board now:** tie `J1..J8.B31` to GND uniformly, and delete the dangling
> one-node net `PRSNT`. ✅ Done for `J1`–`J7`, and the dangling net is gone. ⚠️ **`J8.B31` is
> still unconnected** — one wire left.
>
> Dropping it is what makes the GPIO budget close — see "GPIO budget" below.

### The loop already exists; the motherboard discards it

Each daughterboard shorts `J1.A1` to `J1.B31` on its `PRSNT` net. Those are **diagonally
opposite corners** of the edge connector — the PCIe arrangement, chosen so the loop closes only
when the card is fully *and squarely* seated. A cocked board reads as absent, which is exactly
what you want.

### The change, if it is ever picked up

Keep `A1` on GND; move `B31` on each socket to a Pico GPIO with the RP2040's **internal pull-up**
enabled.

| State | B31 | GPIO reads |
| --- | --- | --- |
| Fully seated | shorted to A1 (GND) by the daughterboard | **LOW** |
| Absent or partially inserted | open | **HIGH** (internal pull-up) |

**Zero new components** — no external resistors, mux, or shift register. Eight net changes on the
motherboard and nothing else. **The daughterboards need no change at all**, which matters given
eight are already populated.

### Pin assignment — does not fit on direct GPIOs

This was originally planned as eight direct GPIOs, on the claim that nine were free
(`GPIO0, 1, 8, 14, 15, 19, 26, 27, 28`). **That count was wrong** — `GPIO8` carries the LDO's
power-good — and `GPIO19` has since gone to `~OE`. Six are actually free (`GPIO0, 1, 14, 15, 27,
28`), which is two short of the eight PRSNT needs.

So if PRSNT is ever picked up, it has to go through the **74HC165 on the CP/PL chain** described
under "GPIO budget", not onto direct pins. That costs one IC and zero GPIOs, and it leaves
`GPIO0/1` free as a debug UART.

Whichever route, the pins are ordinary bank-0 GPIOs with software-selectable internal pull-ups
(~50–80 kΩ), and none carries a conflicting function — the SPI0 (`GPIO2/3/4`) and SPI1
(`GPIO10/11/12`) pinmuxes are untouched.

⚠️ **Do not rely on the pad reset state.** RP2040 pads come out of reset with the input buffer
disabled and a pull-*down* selected, so an unconfigured PRSNT pin reads as "seated." Firmware must
explicitly enable the input buffer and the pull-up before the first read.

### What it buys

Same class of protection as the `3V3_EN` interlock, one level down: **don't drive signals into a
board that isn't properly mated.** Gate SPI and the decoder enables for a slot on its PRSNT bit,
so a half-inserted board never sees clock or chip-select while its power fingers are still making
intermittent contact. That is the real hot-plug hazard — more so than ESD.

It also replaces the current SPI-probe detection with something instant and hardware-true: no
need to talk to a board to find out whether it's there.

Debounce in firmware — require the bit stable for ~10 ms before acting. Contact bounce on
insertion is real. If you ever want more noise margin than the internal pull-up gives across a
connector, add external 10 kΩ; not needed for a static signal.

## GPIO budget — closes comfortably, with PRSNT dropped

⚠️ **Correction to an earlier count.** This document previously claimed nine free GPIOs,
listing `GPIO0, 1, 8, 14, 15, 19, 26, 27, 28`. **`GPIO8` is not free** — it carries the LDO's
power-good via `R6` on the built board. Eight are actually free, which meant the ten-wanted plan
(eight PRSNT + `~OE` + sense) was short by two, not one, and *neither* of the cheap escapes
worked: dropping the +12 V sense still left a shortfall.

Dropping PRSNT resolves it outright:

| Function | Pin | Pico pad | Status |
| --- | --- | --- | --- |
| +12 V sense | `GPIO26` / ADC0 | 31 | to wire |
| `U3.~OE` | `GPIO19` | 25 | to wire (`R9` placed) |
| LDO power-good | `GPIO8` | 11 | built, via `R6` |

That leaves `GPIO0, 1, 14, 15, 27, 28` free — six spare, and `GPIO0/1` stay available as a debug
UART, which matters more than it used to now that the interlock has removed USB-only flashing.
The SPI0 (`GPIO2/3/4`) and SPI1 (`GPIO10/11/12`) pinmuxes are untouched. `GPIO27/28` are
ADC-capable but unused; only `GPIO26` needs its analog function.

**The 74HC165 option is therefore not needed.** It remains the right answer if PRSNT is ever
picked up: the daughterboards already implement a serial chain — `GPIO16` (`CP`) broadcasts to
every `A8`, `GPIO18` (`PL`) to every `A10`, each board's `A11` feeds the next board's `A9`, and
the tail `J8.A11` reads back on `GPIO17`. The head, `J1.A9`, is tied to **GND**, which is a free
insertion point. A '165 reading the eight `B31` pins and driving `J1.A9` appends its byte to the
stream already being shifted: one IC, zero GPIOs, no daughterboard change.

The eight PRSNT pins are **not contiguous**, so firmware assembles the byte from a
`gpio_get_all()` mask rather than a single shift. Making them contiguous would mean re-routing
established, working SPI and decoder traces — not worth it for a few lines of code.

## Component selection

Currents come from the padne per-channel model. **Measure them on the 8-board system before
committing** — the XTR200 quiescent figure is modelled, not measured, and it sizes the tree.

| Rail | Load | Worst case | Design for |
| --- | --- | --- | --- |
| +12 V | 8 boards × 8 ch × (3 mA quiescent + 6 mA pass + 0.6 mA SET) ≈ 80 mA/board | **~640 mA** | 1 A |
| +3.3 V | 8 boards × ~11 mA + motherboard logic ~20 mA (Pico is *not* on this rail) | **~110 mA** | 400 mA |
| 5 V | LDO input ~110 mA + Pico via VSYS ~100 mA | **~210 mA** | 1 A |

**Widening the input range to 15 V does not move these numbers.** The +12 V draw is set by the
DAC-programmed current sources, not by the rail voltage, so the fuse and the converter's input
current are unaffected. What *does* move is dissipation inside the XTR200s: the pass element
drops (V_rail − V_heater), so 12 V → 15 V is roughly +30 % heat per channel, times 64. If 15 V is
only a "must survive it" limit that is fine; if it is an operating point, redo the thermals on the
daughterboard.

### F1 — fuse
PPTC, **1.5 A hold / 3 A trip**, 1812. Auto-recovery matters for a shared lab instrument.

Total +12 V draw is the daughterboards (~640 mA) *plus* the K7805's input current (~100 mA,
below) ≈ **740 mA**. A 1.1 A-hold part derates to ~0.85–0.9 A hold at 40 °C inside an enclosure,
which is uncomfortably close to 740 mA — hence 1.5 A. ~0.1 Ω at 740 mA is 74 mV — negligible.
A 2 A slow-blow cartridge is the alternative if you prefer a hard failure.

The placed part is `1812L150/24MR` — **24 V rated, not the 30 V originally specced**; LCSC stocks
the series only to `/24MR`. Still correct: a fuse's voltage rating is what it must *interrupt*,
which is the 15 V source, not a microsecond TVS transient. (An earlier version of this note
justified 24 V by comparing it against the 21.5 V TVS clamp. With `D2` moving to SMBJ16A that
clamp becomes 26 V, so the comparison no longer holds — but the reasoning above never depended
on it.)

### D2 — transient suppressor
Unidirectional, cathode to +12 V, anode to GND, **between F1 and Q1** so a surge *or* a
reverse-polarity event conducts and blows the fuse — a crowbar backing up the FET.

✅ **Now `SMBJ16A` (`C151254`).** The previously placed `SMBJ13A` was wrong for a 15 V input
range: a 13 V standoff and a 14.4 V *minimum* breakdown means that on a 15 V rail it conducts
continuously and destroys itself. SMBJ15A is not the answer either — its 15 V standoff sits
exactly at the maximum, with no margin for an adapter that idles at 15.4 V.

| Part | Standoff | V_BR min | Clamp | Verdict for a 9–15 V rail |
| --- | --- | --- | --- | --- |
| SMBJ13A | 13 V | 14.4 V | 21.5 V | **conducts continuously — do not fit** |
| SMBJ15A | 15 V | 16.7 V | 24.4 V | zero standoff margin |
| **SMBJ16A** | **16 V** | **17.8 V** | **26.0 V** | **correct** |

26 V still sits below the K7805's 32 V input limit, so the converter survives whatever the TVS
lets through.

⚠️ **Do not "oversize" a TVS by voltage.** Clamping voltage scales with standoff, so a
higher-voltage part passes *more* stress downstream, not less — SMBJ24A would clamp at 38.9 V,
past the K7805's 32 V limit and far past Q1's ±20 V Vgs. It would protect nothing and destroy the
buck. Pick the standoff to the rail and stop.

**Oversize by *power* instead, if you want margin.** `SMCJ16A` is the same 16 V part in the
1500 W SMC package: it clamps *lower* at the same surge current and absorbs more energy. Pure
win, at the cost of board area and a footprint change from `Diode_SMD:D_SMB` to `D_SMC`.

**Unidirectional, not bidirectional.** The rail is DC and single-polarity, so a bidirectional
part's reverse blocking buys nothing — and the forward direction is the whole point. A
unidirectional TVS conducts like an ordinary diode at ~0.9 V when the input is reversed, which
crowbars the reversed adapter and trips F1. That is the **backup for Q1**: if the FET is fitted
backwards, fails short, or the wrong part gets stuffed, the TVS and fuse still catch the event.
SMBJ13**CA** (bidirectional) blocks to −13 V instead and makes Q1 a single point of failure, for
more money and more capacitance.

Consequence to size for: on reverse polarity the TVS dead-shorts the supply through F1, and a
PPTC takes ~0.1–1 s to trip. SMB handles that (IFSM ≈ 100 A / 8.3 ms), but only because the fuse
is **upstream** of the TVS. Wiring the TVS ahead of the fuse removes the only thing that ends the
event — see "Layout notes".

⚠️ **Symbol polarity — still not addressed, despite an earlier ✅ here.** The board originally
drew `D2` with `Device:D_TVS`, the *bidirectional* symbol, whose pins are `A1`/`A2` and which
therefore carries no polarity at all, against a polarized `D_SMB` land pattern. Swapping to
`Diode:SM6T68A` did **not** fix that: its pins are also named `A1`/`A2`. The sheet still cannot
express which end is the cathode.

✅ **The board itself is correct**, verified 2026-08-11 against the PCB: pad 1 of the `D_SMB`
footprint carries the cathode silkscreen bracket and sits on the fused input node with `F1.1`
and `Q1.3` (drain); pad 2 is on GND. Cathode to the rail, anode to GND, TVS between fuse and
FET — as specced. But it is right by land-pattern convention, not because the schematic says so.
Getting this backwards is not a subtle failure: a reversed TVS forward-conducts at ~0.9 V and
shorts the rail on first power-up.

⚠️ **But the symbol name lies.** `SM6T68A` is a 68 V TVS; only the `Value` field (`SMBJ16A`) and
the LCSC field (`C151254`) describe the part actually fitted. That is legal in KiCad and the
netlist is correct, but the next person to read the sheet will be misled. Either rename via a
local symbol or accept it deliberately — see "Schematic hygiene".

### Q1 — reverse-polarity protection
P-channel MOSFET, high side. **Drain to the supply, source to the load.**

Not optional with this converter: the K78xx-500R3 datasheet lists "Reverse Polarity at Input:
**Avoid / Not protected**". A reversed barrel jack destroys the module directly.

- *Correct polarity*: the body diode (drain→source) conducts first, the load rises, so
  Vgs = 0 − V_load goes strongly negative and the FET turns on hard, shorting out its own diode.
- *Reversed*: the body diode is reverse-biased and Vgs ≈ 0 — nothing conducts.

Source-to-supply is the common mistake, and it fails *silently*: the body diode forward-biases
on reverse polarity and passes current anyway, so the circuit tests fine and doesn't protect.

Selected: **Q1 = AO3407A** (LCSC `C15155`) — −30 V Vds, −4.3 A, 48 mΩ, SOT-23, **Vgs ±20 V**,
~150 k in stock at ~$0.10 (clone versions `C181093`/`C727158` at ~$0.016). At 740 mA / 48 mΩ
that's 36 mV and 26 mW, against ~0.33 W for a series Schottky.

| Ref | Part | Role |
| --- | --- | --- |
| `R1` | 100 kΩ (`C96346`) | Gate → GND. Turns Q1 on when polarity is correct. Placed. |
| `D6` | **BZT52C18** (`C192739`, 18 V zener, SOD-123) | Gate–source clamp, cathode to source. ✅ Placed and valued; verified `K` → `+12V` (Q1 source), `A` → Q1 gate + `R1`. |

**Why not AO3401A** (the obvious, cheapest choice, and what earlier drafts of this spec
selected): it is rated **Vgs ±12 V**. With the gate pulled to GND on a 12 V rail, Vgs sits at
exactly −12 V *continuously* — at the absolute maximum, with zero margin, and over it on any
adapter that idles above 12.0 V. AO3407A is the same package and pinout with 8 V of Vgs
margin, so the whole problem disappears for ~$0.08.

⚠️ **The symbol still says `AO3401A`.** `Q1` is drawn with `Transistor_FET:AO3401A` and valued
`AO3407A` (`C15155`, the correct part). Same pinout and package, so the board is right — but
given that the *entire* reason for choosing the 3407 is its Vgs rating, a sheet that names the
3401 is a trap. See "Schematic hygiene".

### D6 — why the gate zener is now required, not optional

At a 12 V rail this was a documented corner worth skipping: Vgs = −12 V against ±20 V left 8 V of
margin, and the SMBJ13A's 21.5 V clamp only occurs at its full 600 W / ~100 A rating — a bench
adapter's surge energy clamps nearer 14–17 V, inside the rating.

**A 15 V rail closes that margin from both directions.** Vgs sits at −15 V continuously (5 V of
headroom), and the SMBJ16A clamps as high as **26 V** — straight through the ±20 V rating rather
than near it. Fit the clamp.

**Use BZT52C18 (18 V), not the BZT52C15 this document specced for 12 V.** The value is boxed in
on both sides and 18 V is the only comfortable fit:

- It must sit **above 15 V** so it never conducts in normal operation. A 15 V part on a 15 V rail
  idles on its knee (V_z spread 13.8–15.6 V), which makes it load-bearing rather than protective —
  exactly the objection that ruled out a 10 V part at 12 V.
- It must sit **below 20 V** to clamp inside Q1's Vgs rating. BZT52C18's V_z spread is
  16.8–19.1 V, so even the worst-case unit clamps under the limit.

Power rating is irrelevant here — the clamp never carries more than (26 − 18)/100 kΩ ≈ 80 µA
through `R1`, so the smallest 200 mW part is already a thousandfold overrated. There is nothing to
gain by oversizing `D6`; only the voltage matters, and it has one right answer.

**Why not N-channel** (low-side, in the ground return): two reasons, the first fatal here.

1. **The Pico's USB connector bonds board GND to PC GND**, giving ground a second path that
   bypasses the FET entirely. The protection does nothing whenever USB is plugged in — and on a
   reversed jack the return current routes through the USB cable into the host.
2. It inserts Rds(on) × 740 mA of offset between supply GND and board GND, in the return path
   the AD7193 measures against.

It also has the identical Vgs problem (gate to +12 V, source at supply ground → Vgs = +12 V), so
it buys nothing even ignoring the above.

### Bulk — electrolytic on +12 V

**220 µF / 35 V** aluminium electrolytic on the +12 V rail after Q1. Two jobs:

1. **Load step.** 64 channels enabling at once is a ~600 mA step, supplied from board capacitance
   until the adapter's loop and the cable inductance catch up (~50–200 µs). ΔV ≈ I·Δt/C: 220 µF
   gives ~0.27 V, 100 µF ~0.6 V, and a lone 1 µF ceramic lets the rail collapse. This is a
   measurement instrument — a rail that sags under full load shows up as an accuracy mystery.
2. **Hot-plug damping.** Plugging the jack rings a metre of cable inductance against the board
   capacitance. Pure ceramic has no ESR to damp it and can transiently reach ~2× the supply; the
   TVS would clamp that, but then it eats energy on every plug-in. **Keep real ESR — do not
   substitute a large MLCC.** Critical damping wants R ≈ 2√(L/C) ≈ 135 mΩ at 1 µH / 220 µF; the
   part below is 80 mΩ, which with cable resistance gives Q ≲ 1 and essentially no overshoot.

**Use 35 V, not 25 V.** ✅ The placed `C7` is 35 V (`C125981`). The case for it only got stronger:
with `D2` at SMBJ16A the clamp is **26 V**, and standard ~80 % electrolytic derating puts a 25 V
part at 20 V — well under the clamp, and now under the *continuous* headroom you'd want on a
15 V rail too.

⚠️ **Check `C5` while you are here.** It sits directly on the +12 V rail as the K7805's input
capacitor, and the netlist carries no voltage rating. The specced part (`C77102`) is 50 V, which
is correct — confirm that is what the schematic field actually says. A 25 V X5R at 15 V DC bias
would lose over half its capacitance, and Table 1's 10 µF is a switching-loop requirement rather
than decoupling by habit.

This does not replace the K7805's own input capacitor; that is a separate Table 1 requirement.
680 µF is the module's max capacitive load on its *output*, so it doesn't constrain this.

### Capacitor part numbers

Verified on LCSC. Ceramics are specced **above** the datasheet's nominal voltage on purpose:
DC bias derating costs an X5R most of its capacitance near its rating, so a 10 V-rated 22 µF at
5 V is really ~11 µF, while the 25 V part holds most of its value.

**Mixed case sizes, by design.** There is no single-size rule on this board: each ceramic is
sized for its job — 0603 for the 100 nF decouplers and the sense filter, 0805 for the 10/22 µF
regulator caps, 1210 for `C5`. An earlier draft of this document specced a blanket 0805
standardisation; it was never carried out and is not wanted.

**Refdes below are as built** — this table previously used the pre-rework numbering; see "Refdes
drift" at the top if you are cross-referencing an older revision of this document.

| Ref | Role | Value / package | Brand & MPN | LCSC |
| --- | --- | --- | --- | --- |
| `C7` | +12 V bulk | 220 µF 35 V, Ø8×10 mm can, `Capacitor_SMD:CP_Elec_8x10` | Nichicon `UWT1V221MNL1GS` | **`C125981`** |
| `C5` | K7805 input (Table 1) | 10 µF 50 V X7R **1210** | Murata `GRM32ER71H106KA12L` | **`C77102`** |
| `C6` | K7805 output (Table 1) | 22 µF 25 V X5R 0805 | Samsung `CL21A226MAQNNNE` | **`C45783`** |
| `C8`, `C9` | LDO in / LDO out | 10 µF 25 V X5R 0805 | Murata `GRM21BR61E106KA73L` | **`C84416`** |
| `C1`–`C4` | Per-IC decoupling | 100 nF 50 V X7R **0603** | Samsung `CL10B104KB8NNNC` | **`C14663`** |
| `C10` | +12 V sense filter | 100 nF 50 V X7R **0603** | Samsung `CL10B104KB8NNNC` | **`C14663`** |

**Why the bulk values are not 0603:** 0603 tops out near 10 µF at 6.3–10 V. Neither 22 µF/25 V
nor 10 µF/50 V exists in that case size, so `C5`/`C6`/`C8`/`C9` have to be larger regardless.
100 nF in 0603 is unaffected by any of that, which is why the decouplers stay small.

**Why `C5` is 1210.** DC bias derating worsens as the case shrinks — same voltage rating in a
smaller package means thinner dielectric — and the 0805 50 V part is X5R where the 1210 is X7R,
the more bias- and temperature-stable dielectric. `C5` sits on the +12 V rail, up to 15 V here,
where an 0805 would keep roughly half its 10 µF. Table 1's 10 µF is a requirement of the module's
input switching loop, not decoupling by habit, so undershooting it is a real compromise. The 0805
option (`GRM21BR61H106KE43L`, `C440198`) is also 3× the price for less delivered capacitance —
$0.325 vs $0.114.

Ceramics are specced **above** the datasheet's nominal voltage on purpose: an X5R loses most of
its capacitance near its rating, so a 10 V-rated 22 µF at 5 V is really ~11 µF while the 25 V
part holds most of its value.

A THT bulk alternative exists — Nichicon `UHE1V221MPD6`, **`C251010`**, D10×L12.5 mm, 5 mm pitch,
80 mΩ, 865 mA, 7000 h @105 °C — but it won't be machine-placed if the board goes through JLCPCB
assembly.

### U6 — 12 V → 5 V converter
Selected: **K7805-500R3** (EVISUN, LCSC `C19188491`, ~$1.07, SIP-3) — a drop-in switching
replacement for the LM78xx, which is exactly how it is being used here.

| Spec | Value |
| --- | --- |
| Input | 6.5–32 V (EVISUN spec; Mornsun original 6.5–36 V) |
| Output | 5 V ±2 %, **500 mA** |
| Efficiency | ~89 % at 12 V in, full load |
| Ripple & noise | 20 mVp-p typ, 75 mVp-p max (20 MHz BW) |
| Switching frequency | 550–850 kHz (EVISUN datasheet quotes 520 kHz) |
| Package | SIP-3, 11.60 × 7.55 × 10.16 mm, 2.54 mm pitch |
| Pinout | **1 = Vin, 2 = GND, 3 = +Vout** — identical to LM78xx |

At the ~210 mA 5 V load that's ~1.05 W out / ~1.18 W in ≈ **98 mA from +12 V**, and 2.4×
current headroom. Derating is flat to 71 °C ambient; no heatsink.

**Pin compatibility is the whole point of picking it:** U6's nets (`+12V` → pin 1,
GND → pin 2, `+5V` → pin 3) are already correct. The only schematic change is the symbol/value,
and the only layout change is the footprint.

**Symbol and footprint — use the TRACO TSR-1 pair from stock KiCad libraries.** No custom
drawing and no SnapMagic import needed:

| | Use |
| --- | --- |
| Symbol | `Converter_DCDC:TSR_1-2450` — pin 1 `Vin` (power_in), 2 `GND`, 3 `Vout` (power_out) |
| Footprint | `Converter_DCDC:Converter_DCDC_TRACO_TSR-1_THT` (the symbol's default, so it fills in automatically) |

Override the `Value` field to `K7805-500R3`. Verified against the Mornsun datasheet's recommended
layout:

- **Pads**: 3 × through-hole at 2.54 mm pitch, **drill Ø1.00 mm**, pad 1.5 × 2.5 mm. The
  datasheet specifies Ø1.00 mm holes on a 2.54 mm grid — exact match.
- **Pinout**: TRACO TSR-1 is 1 = Vin, 2 = GND, 3 = Vout, identical to the K7805 (both are LM78xx
  drop-ins).
- **Outline**: the footprint's fab layer is 11.94 × 7.85 mm against the K7805's 11.60 × 7.55 mm —
  0.3 mm generous on each axis, so the silkscreen is slightly larger than the part. Cosmetic.

The pre-rework `Package_TO_SOT_THT:TO-220F-3_Vertical` was wrong on both counts: TO-220 is 10.16 mm
wide with a mounting tab, and its holes are sized for 0.5 × 1.0 mm blades rather than the K7805's
0.50 mm pins.

Required external capacitors (datasheet Table 1, ceramic, as close to the pins as possible):

| Ref | Value | Node |
| --- | --- | --- |
| `C8` | **10 µF / 50 V** | pin 1 (Vin) → GND |
| `C9` | **22 µF / 10 V** | pin 3 (Vout) → GND |

These are *required*, not decoupling-by-habit — the module has no internal input filter beyond
what Table 1 assumes. Add 100 nF alongside each if you want HF bypass.

If 5 V ripple ever turns out to matter, the datasheet's note 5 offers an LC output filter
(10–47 µH + 22 µF). It shouldn't: the LP5912 downstream has ~40 dB PSRR at 500 kHz, and a
20 mVp-p input becomes sub-mV on +3.3 V.

### D1 — 5 V → VSYS
Schottky, 40 V / 1 A, low Vf (SS34, already placed, SMA). Anode to the +5 V rail, cathode to
VSYS. VSYS lands ~4.7 V — well inside the Pico's 1.8–5.5 V range — and ORs cleanly against the
module's internal VBUS diode. Note the K7805 is fixed-output, so unlike an adjustable buck you
cannot trim it to 5.3 V to land VSYS at exactly 5 V; 4.7 V is fine.

The K78xx datasheet's "cannot be used with outputs in parallel" warning does **not** apply here —
D1 is a diode-OR into VSYS against the Pico's internal VBUS diode, not two converters sharing a
node.

### U4 — 5 V → 3.3 V LDO
Placed: **LP5912-3.3DRV** (WSON-6, thermal pad) — 500 mA, low noise, high PSRR, with an enable
pin (currently tied to +5 V) and a power-good output (already routed to `GPIO8` via R6).

Feeds AD7193 AVDD and DAC80508 on every daughterboard, so PSRR is the spec that matters; the
LP5912 is the quiet end of the range and is a better choice than the AP2112K originally specced
here. Its thermal pad also solves the dissipation question below. 500 mA against a ~115 mA load
is >4× headroom.

Its input range is **2.2–5.5 V** — it cannot be fed from 12 V, which is precisely why U6 exists
rather than a single linear stage.

✅ **Required caps — fitted.** Both are 10 µF `C84416`, above the datasheet's 1 µF minimum:

| Ref | Value | Node |
| --- | --- | --- |
| `C8` | 10 µF ceramic | IN → GND, at the pin |
| `C9` | 10 µF ceramic | OUT → GND (datasheet minimum is 1 µF; 10 µF for the connector bank) |

**Thermals:** 1.7 V × 110 mA ≈ **0.19 W**. In WSON-6 with the exposed pad soldered to a
via-stitched pour this is a non-issue; keep the thermal vias in the footprint.

### Decoupling
100 nF per IC power pin — two '138s, the '595, the TMUX1208 — plus 10 µF near the connector
bank, and the regulator caps above.

The board carries `C1`–`C4` (100 nF) plus `C9` (10 µF) on +3.3 V. That is four 100 nF against
four ICs, so it is one-per-IC only if they are placed one-per-IC — check that in layout rather
than assuming it from the count. There is **no** bulk ceramic at the +3.3 V connector bank beyond
`C9`, and none at the +12 V bank at all; the +12 V side leans on `C7`'s 220 µF, which is upstream
by the regulator rather than out at the sockets.

⛔ **The extra 10 µF at the far end of the connector bank is skipped (2026-08-11).** `C9` plus
the daughterboards' own local decoupling carry it; each board brings its own bulk behind its
edge fingers.

## Layout notes

- `C5`/`C6` hard against U6's pins 1 and 3 — the datasheet is explicit about this, and the
  module's switching loop closes through them.
- Protection chain physically ordered jack → F1 → TVS → Q1, short and wide. A TVS on a long
  trace clamps its own inductance instead of the transient.
- Keep `R7`/`R8` close to the Pico's pin 37; it's a high-impedance node and shouldn't run
  alongside the SPI clocks.
- U6 is a shielded module, but keep its ground return tight and don't run the +12 V sense divider
  or `MISO_0/1` under it.
- Copper pour under the LDO's thermal pad, stitched to the plane with a via array.
- Keep +12 V and 5 V return currents off the analog reference path to the edge connectors.

## Rejected alternatives

- **Tying Pico 3V3 (pin 36) to the +3.3 V rail.** Parallels the RT6150 against the LDO with no
  droop sharing — whichever regulates higher carries everything until it current-limits.
- **Disabling the regulator and feeding 3V3 externally.** Documented by Raspberry Pi, but
  conditional on VSYS being unpowered, which USB makes impossible to guarantee.
- **Firmware GPIO gating alone.** Leaves protection dependent on correct firmware, and permits a
  half-powered board state that shouldn't be reachable at all.
- **`74LVC541`/`125` Ioff buffers at the boundary.** Correct and conventional, but ~3 ICs plus
  17 pull resistors to solve a problem the interlock removes for two resistors. Reconsider only
  if USB-only firmware flashing turns out to matter.

## Schematic hygiene while you're in there

Three symbol/value mismatches. In every case KiCad takes the net name and the BOM line from the
`Value` and `LCSC` fields, so **the netlist and the board are correct** — but the sheet reads
wrong, and one of them is genuinely dangerous to leave.

| Ref | Symbol on the sheet | Actual part | Why it matters |
| --- | --- | --- | --- |
| `Q1` | `Transistor_FET:AO3401A` | AO3407A (`C15155`) | ⚠️ **Still open — fix this one.** The whole reason for the 3407 is its ±20 V Vgs; the 3401 is ±12 V and would be over its absolute maximum on a 15 V rail. A sheet naming the 3401 invites someone to "correct" the BOM to match. |
| `D2` | `Diode:SM6T68A` | **SMBJ16A** (`C151254`) | ⚠️ **Still open.** SM6T68A is a 68 V part, *and* its pins are `A1`/`A2`, so it does not even buy the polarity it was chosen for. |
| `U3` | `74xx:74HC595` | SN74LV595 (`C116847`) | Harmless — same pinout and function. |
| `D6` | `Diode:BZT52Bxx` | BZT52C18 (`C192739`) | Harmless — generic zener symbol, correctly valued and sourced. |

✅ `#PWR050` and `#PWR036` are fixed — no power symbol on the sheet now has a `Value` that
disagrees with its graphic.

## Build checklist

### Sourcing — every part in the schematic

Verified on LCSC. Rows marked *(BOM)* are already in `master_bom_lcsc.csv`.

| Ref | Part | LCSC | Footprint |
| --- | --- | --- | --- |
| `A1` | Raspberry Pi Pico *(BOM)* | `C7203003` | — |
| `U1`, `U5` | **SN74HC138PWR** (TI) — replaces SN74LVC138APWR, see below | `C157527` | `Package_SO:TSSOP-16_4.4x5mm_P0.65mm` |
| `U2` | TMUX1208PW | ✅ **`C494728`** | TSSOP-16 |
| `U3` | SN74LV595APWR *(BOM)* | `C116847` | TSSOP-16 |
| `U4` | LP5912-3.3DRVR (TI) | `C524780` | WSON-6 |
| `U6` | K7805-500R3 (EVISUN) | `C19188491` | `Converter_DCDC:Converter_DCDC_TRACO_TSR-1_THT` |
| `Q1` | AO3407A (AOS, Vgs ±20 V) | `C15155` | SOT-23 |
| `D1` | SS34 (MDD) | `C8678` | `Diode_SMD:D_SMA` |
| `D2` | SMBJ16A (Littelfuse) — replaced SMBJ13A (`C133675`) | ✅ **`C151254`** | `Diode_SMD:D_SMB` |
| `D3`–`D5` | Rail LEDs (+12 V / +5 V / +3.3 V) | `C157740` | `LED_SMD:LED_0603_1608Metric` |
| `D6` | BZT52C18-7-F (Diodes Inc) — Q1 gate clamp | ✅ **`C192739`** | `Diode_SMD:D_SOD-123` |
| `F1` | 1812L150/24MR (Littelfuse) | `C142805` | 1812 |
| `R1`, `R6` | 100 kΩ 0805 1% (Yageo `RC0805FR-07100KL`) | `C96346` | `Resistor_SMD:R_0805_2012Metric` |
| `R2`, `R8` | 4.7 kΩ 0805 | `C431850` | `R_0805_2012Metric` |
| `R3` | 1.5 kΩ 0805 | `C4310` | `R_0805_2012Metric` |
| `R4` | 680 Ω 0805 | `C17798` | `R_0805_2012Metric` |
| `R7`, `R9` | 10 kΩ 0805 | `C84376` | `R_0805_2012Metric` |
| `J1`–`J8` | Samtec PCIE-064-02-F-D-TH *(BOM)* | `C4597619` | — |
| `J9`–`J11` | ✅ Hirose FH12-50S-0.5SH — replaces the un-stocked Molex 54132-5033 | `C202116` | `Hirose_FH12-50S-0.5SH_1x50-1MP_P0.50mm_Horizontal` |
| `J12` | DC005-T20 barrel jack *(BOM)* | `C84007` | — |
| `J13` | 1×2 pin header, +12 V | — | `PinHeader_1x02_P2.54mm_Vertical` |

Capacitors are in "Capacitor part numbers" above.

✅ **`D2` and `D6` are now sourced.** Both looked up on LCSC 2026-08-11 and set in the schematic:

- **`D2` = Littelfuse SMBJ16A, `C151254`** — 16 V standoff, V_BR 17.8–19.7 V, 26 V clamp, 600 W
  10/1000 µs, unidirectional, DO-214AA. Branded on purpose: LCSC lists SMBJ parts from a dozen
  no-name houses at a third of the price, and clamping voltage is exactly the spec generics are
  loosest about.
- **`D6` = Diodes Inc BZT52C18-7-F, `C192739`** — 18 V, V_z spread 16.8–19.1 V, 500 mW, SOD-123.
  A generic would be fine here (it carries microamps into a gate); the branded part costs
  cents.

**Note the `D6` footprint is plain `D_SOD-123`, not `SOD-123F`.** Every BZT52C18 on LCSC —
Diodes Inc, LGE `C545295`, JSCJ `C43490`, YONGYUTAI — is standard SOD-123; the `BZT52C18S` parts
that surface in a search are SOD-323, a different package. The board was corrected to match.

Two sourcing questions this document used to flag are now **closed**: `U2` (TMUX1208PW) resolved
to `C494728`, and `J9`–`J11` moved off the un-stocked Molex part to a stocked Hirose equivalent.

**`U1`/`U5`: use `SN74HC138PWR` (`C157527`), not `SN74LVC138APWR` (`C485077`).** The LVC part is
**$0.755 at 1+ with 669 in stock**; the HC part is **$0.095 with ~50 000 in stock** — 8× cheaper
and not a sole-source risk. Nothing in this design needs LVC:

- The decoders are static during a transfer. Firmware sets the address on `GPIO20/21/22`, asserts
  `ADC_EN`/`DAC_EN`, *then* clocks SPI — the decoder never switches at bus speed, so HC's ~50 ns
  worst-case t_pd at 3.3 V is setup time that's already covered by the intervening instructions.
- Each `Y` output drives one daughterboard CS input through the edge connector — microamps plus
  trace capacitance, against HC's ~5 mA drive.
- HC's 2–6 V range covers the 3.3 V rail, and V_IH = 0.7 × V_CC = 2.31 V against the RP2040's
  3.3 V CMOS output.

LVC would only earn its price if the decoders had to switch at SPI speed or run below 2 V.
Nexperia `74HC138PW,118` (`C47455`, $0.082) is an equally good second source.

✅ **Both are resolved on the board.** `U1`/`U5` are `SN74HC138PWR` (`C157527`) in
`TSSOP-16_4.4x5mm_P0.65mm`, so all four logic ICs (`U1`, `U2`, `U3`, `U5`) now share one
footprint. The old `Package_SO:SSOP-16_5.3x6.2mm_P0.65mm` (TI's DB package) is gone.

The `master_bom_lcsc.csv` row may still read `SN74LV138 (74HC138)` mapped to `SN74LVC138APWR` —
three different logic families in one line. Update it against `production/bom.csv`.

**Pick branded parts for `D2` and `F1` deliberately** — see the note under the sourcing table.

### Still to add

**Nothing.** ✅ The sense divider went in as `R5` (100 kΩ, `C96346`), `R10` (22 kΩ, `C114565`)
and `C10` (100 nF 0603, `C14663`), and every other item this table used to list has been
deliberately dropped:

| Dropped | Why |
| --- | --- |
| `ADC_EN` / `DAC_EN` 10 kΩ pull-ups | Decision 2026-08-11 — see "Board-side defaults" |
| `U2` EN 10 kΩ pull-down | Same; was always optional |
| 10 µF at the J1–J8 +3.3 V bank | Decision 2026-08-11 — see "Decoupling" |
| `BAT54S` sense clamp | The 100 kΩ top leg makes it unnecessary — see "Rail sensing" |

The one open suggestion is extra 100 nF (`C14663`) on any IC power pin that turns out not to
have one — a layout check, not a known gap.

### Changes to placed parts

| Ref | From | To | Status |
| --- | --- | --- | --- |
| `D2` | `SMBJ13A` (`C133675`) | **`SMBJ16A`** (`C151254`) | ✅ done |
| `D6` | `BZT52Bxx` placeholder, no LCSC | **`BZT52C18`** (`C192739`), footprint `D_SOD-123` | ✅ done |
| `U3.13` (`~OE`) | hardwired to GND | `GPIO19` (A1 pad 25), with `R9` pulling up to +3.3 V | ✅ done |
| `Q1` | symbol `Transistor_FET:AO3401A` | a symbol that names the AO3407A actually fitted | ⚠️ open |
| `D2` | symbol `Diode:SM6T68A` (pins `A1`/`A2`) | a genuinely polarized symbol | ⚠️ open |
| `C5` | — | the `Value` field is bare `10uF`; `C77102` is the correct 50 V 1210 part, so BOM and fab are right | cosmetic |

Already done in `397a4a4`: the `U8`→`U6` K7805 swap, `C7` to a polarized `CP_Elec_8x10`, `C5` to
1210, `R7` 100 k→10 k, and `R8` 100 k→4.7 k with its far end moved from A1 pin 36 to `+3.3V`.
*(An earlier version of this line also claimed a 0603→0805 ceramic standardisation landed in
`397a4a4`. It did not — `C1`–`C4` are 0603 — and the board no longer wants one.)*

### Net changes

- ✅ `+12V` ← Q1 source. Done.
- ✅ `A1.31` (GPIO26/ADC0) ← `12V_SENSE`. Done.
- ✅ `A1.25` (GPIO19) ← `U3.13`, tie to GND cut. Done — net `~{OE}` = `U3.13` + `A1.25` + `R9.1`.
- ⚠️ `J1..J8.B31` → GND: **seven of eight done.** `J1`–`J7` are on GND and the dangling one-node
  `PRSNT` net is gone; **`J8.B31` is still unconnected.**

`R6`/`PG` on `GPIO8` **stays**. An earlier version of this list proposed dropping it to free the
pin for PRSNT — with PRSNT deferred there is nothing to free it for, and six GPIOs are spare
regardless.

## Firmware follow-up

Changes in `firmware/motherboard-test/` that this revision implies:

- Drive `GPIO19` (`~OE`) — hold high or leave as an input on `R9` until the first `0xFF` has been
  shifted and latched into `U3`, then drive low.
- Read `GPIO26` and report the +12 V rail in the identify/status response; refuse `ISET`/enable
  commands when it is out of range, with a distinct error. `V12 = adc_volts * 5.5455`.
- Nothing to do for PRSNT — the feature is deferred.

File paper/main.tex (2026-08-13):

% =====================================================================
%  HardwareX manuscript -- Koi 8x8
%  Draft skeleton. Final submission should use the official HardwareX
%  elsarticle template (els-cas-templates). This article-class version
%  is for drafting + sharing a compilable PDF.
%
%  Build:  make        (or  pdflatex main.tex  twice)
%  TODOs:  search for \todo{...} -- these mark data/text still to add.
% =====================================================================
\documentclass[11pt]{article}

\usepackage[a4paper,margin=2.4cm]{geometry}
\usepackage{amsmath}
\usepackage{booktabs}
\usepackage{tabularx}
\usepackage{longtable}
\usepackage{array}
\usepackage{graphicx}
\usepackage{xcolor}
\usepackage{caption}
\usepackage{enumitem}
\usepackage[hidelinks]{hyperref}

% --- editing helpers --------------------------------------------------
% \todo{...} marks something to fill in; renders in red. Set \draftfalse
% (or comment the \drafttrue line) to hide them for a clean read.
\newif\ifdraft\drafttrue
\newcommand{\todo}[1]{\ifdraft{\color{red}\textbf{[TODO: #1]}}\fi}
\newcommand{\note}[1]{\ifdraft{\color{blue!60!black}\textit{(#1)}}\fi}

\newcolumntype{L}[1]{>{\raggedright\arraybackslash}p{#1}}

% --- placeholder plot box ---------------------------------------------
% \plotph{width}{height}{Plot title} draws a titled, hatched placeholder so
% the figure layout is reviewable before real data exists. Swap each call
% for \includegraphics{figures/...} once the plot is generated.
\newcommand{\plotph}[3]{%
  \setlength{\fboxsep}{0pt}%
  \fbox{\parbox[c][#2][c]{#1}{\centering
    \color{black!55}\ttfamily\small #3\\[2pt]
    \color{black!35}\scriptsize[placeholder --- awaiting data]}}}

\title{\textbf{Koi 8$\times$8: A low-cost 64-channel current-source-and-sense controller for thermo-optic phase shifters in photonic integrated circuits}}
\author{%
  Rohan Yadgirkar\thanks{Corresponding author: \texttt{rohany@kth.se}}\quad Ali Elshaari\\[4pt]
  \normalsize KTH Royal Institute of Technology, Stockholm, Sweden\\[2pt]
  \small\texttt{rohany@kth.se}\quad\texttt{elshaari@kth.se}%
}
\date{Draft --- \today}

\begin{document}
\maketitle

\begin{abstract}
This article describes the development of \emph{Koi 8$\times$8}, a compact,
low-cost, open-source 64-channel current-source-and-sense controller for
driving arrays of thermo-optic (TiN) phase shifters on photonic integrated
circuits. The system is built entirely from off-the-shelf parts: a Raspberry
Pi Pico controls up to eight stackable daughterboards, each combining an
8-channel DAC, a 24-bit $\Sigma\Delta$ ADC, and eight precision industrial
current transmitters operated as current sources. Each channel sources a
programmed current and reads back the load voltage, so the host computes
heater resistance and dissipated power in situ for closed-loop tuning. On
each board the DAC and ADC share one precision reference, so the reference
error cancels in the derived resistance; a one-time calibration against a
reference source-measure unit recovers absolute accuracy. Complete hardware,
firmware, host software, and calibration tooling are released under open
licenses.
\end{abstract}

% =====================================================================
\section*{Specifications table}
% HardwareX requires this table verbatim near the front.
\renewcommand{\arraystretch}{1.3}
\noindent\begin{tabularx}{\textwidth}{@{}L{3.6cm} X@{}}
\toprule
Hardware name & Koi 8$\times$8 --- 64-channel current-source-and-sense controller \\
Subject area &
\begin{minipage}[t]{\linewidth}
\begin{itemize}[nosep,leftmargin=1.2em]
  \item Engineering and materials science
  \item Optics and photonics \note{select final categories from the HardwareX list}
\end{itemize}
\end{minipage}\\
Hardware type &
\begin{minipage}[t]{\linewidth}
\begin{itemize}[nosep,leftmargin=1.2em]
  \item Electrical engineering and computer science
  \item Measurement / instrumentation and control
\end{itemize}
\end{minipage}\\
Closest commercial analog & Multichannel source-measure systems for photonic biasing, e.g.\ Qontrol Q8iv/BP modules and multi-channel Keithley 2400-class SMUs. \todo{confirm exact comparison products + prices} \\
Open source license & Hardware: CERN-OHL-S v2; Firmware/software: MIT \note{confirm} \\
Cost of hardware & \todo{total build cost from BOM; per-channel cost} \\
Source file repository & \todo{Zenodo DOI} (mirror: \todo{GitHub URL}) \\
\bottomrule
\end{tabularx}
\renewcommand{\arraystretch}{1.0}

% =====================================================================
\section{Hardware in context}
\label{sec:context}

Programmable photonic integrated circuits (PICs) have become a central platform
for optical communications, sensing, microwave photonics, and increasingly for
optical computing and quantum information
processing~\cite{bogaerts2020programmable}. What makes these circuits
\emph{programmable} is a dense fabric of tunable elements --- meshes of
Mach--Zehnder interferometers and ring resonators whose phase is set
electrically~\cite{bogaerts2020programmable,clements2016optimal}. The dominant
tuning mechanism is the thermo-optic effect: a resistive micro-heater, commonly
a titanium-nitride (TiN) filament patterned over the waveguide, dissipates
electrical power and locally shifts the refractive
index~\cite{harris2014efficient}. A single modern device can
integrate from tens to several hundred such heaters, and each must be held at an
independent, stable bias for the circuit to hold a programmed state.

Two requirements make driving these heaters non-trivial at scale. First, the
relevant control variable is dissipated \emph{power}, not drive current, and the
heater resistance drifts with temperature and ages over time; robust operation
therefore benefits from reading back the voltage across each heater so that
resistance and power can be computed and servoed in situ, rather than driven
open-loop~\cite{milanizadeh2019canceling}. \note{verify this closed-loop cite
fits; alternatives: Padmaraju \& Bergman thermal-stabilization review.} Second,
the channel count is large. Driving every heater from a laboratory
source-measure unit (SMU) is accurate but prohibitively expensive and bulky
beyond a handful of channels. Dedicated solutions exist at both ends of the
spectrum: commercial multichannel driver modules
(e.g.\ Qontrol~\cite{qontrol_q8a,qontrol_q8iv}) offer dense drive with optional
readback but at a substantial per-channel cost, while research-grade custom
CMOS controllers~\cite{sacchi2025controller} demonstrate excellent density and
power but require ASIC fabrication and are not reproducible open hardware. On
the open-source side, source-measure designs are typically single-channel
bench instruments (e.g.\ the uSMU~\cite{troughton_usmu}); to our knowledge no
published open design combines dense multichannel current drive with
per-channel voltage readback at the scale photonic meshes need. \todo{sweep
HardwareX/JOSS/OSF for further open multichannel drivers before submission ---
reviewers will check that prior open hardware is cited.} There remains a need
for a low-cost, fully open, and readily reproducible controller that combines
dense current drive with per-channel readback.

This paper presents \emph{Koi 8$\times$8}, an open-source controller named for
its stack topology --- eight stackable daughterboards of eight channels each,
not any particular photonic mesh geometry --- that drives up to \textbf{64
independent current-source channels} and measures the
voltage developed across each load, so the host can compute per-channel
resistance and power in situ. The design targets the accuracy regime that
matters for heater tuning: \emph{relative / ratiometric} accuracy. Each
daughterboard carries its own precision voltage reference (eight in total),
shared by that board's DAC and ADC, so the commanded drive and the measured
readback are scaled by the same reference and its error cancels in the derived
resistance; channels on the same board are additionally compared against the
same reference, so common-mode errors cancel between adjacent tuning elements.
Board-to-board matching is bounded by the reference initial tolerance and is
characterized in Section~\ref{sec:validation}. \todo{report measured
board-to-board reference spread (REF5030, $\pm$0.05\,\% initial tolerance)
alongside the calibration data.} Absolute accuracy is available through an
optional one-time calibration against a reference SMU.

\paragraph{Contribution.}
\begin{itemize}[nosep]
  \item A stackable controller + daughterboard architecture scaling from 8 to
        64 channels from commodity parts (RP2040, DAC80508, AD7193, XTR200).
  \item Per-channel closed-loop readout enabling in-situ $R$ and power
        measurement, with an analytic correction for the on-board sense
        divider current.
  \item A fast continuous-conversion scan that reads the full 64-channel array
        in \textbf{0.46\,s} (measured, Section~\ref{sec:throughput}), gated by
        filter settling rather than by a per-channel restart penalty.
  \item Open hardware, firmware, host software, and calibration tooling.
\end{itemize}

% =====================================================================
\section{Hardware description}
\label{sec:description}

\todo{Figure: system block diagram (controller + 8 daughterboards, SPI buses,
decoders). Place as figures/block\_diagram.pdf.}

The system is a host-commanded instrument. A PC sends per-channel current
setpoints (in mA) over USB serial; the firmware sources the commanded current
through each load and reports the measured voltage, from which the host
computes resistance and power.

\subsection{Signal chain (per channel)}
Each of the 64 channels is an independent loop: an 8-channel DAC sets the input
of a precision industrial current transmitter (Texas Instruments XTR200, a
3-wire current/voltage transmitter) operated as a current source, the sourced
current flows through the external load (a TiN heater in the target
application) to ground, and an 8-channel 24-bit $\Sigma\Delta$ ADC measures the
voltage developed across the load through a 6:1 input divider.

Using an industrial transmitter outside its headline 4--20\,mA niche is a
deliberate design choice, and it is what makes the channel density affordable:
the XTR200 integrates the complete precision output stage in one commodity
package ($\sim$US\$1.5), absorbs the sourcing dissipation in a part designed
for continuous industrial drive, and its datasheet figures --- span error
$\le\pm0.065$\,\%, nonlinearity $\pm0.003$\,\%, output impedance 47\,G$\Omega$
--- match or beat a discrete op-amp current source that would cost more board
area, calibration effort, and thermal management per channel. Eight sources
per daughterboard therefore add no exotic parts and no heatsinking. The
design's economy comes not from a new circuit but from recognizing that a
mass-manufactured industrial part --- cheap because it is produced in volume
for a market far larger than laboratory instrumentation --- already integrates
the entire precision source channel; the contribution is the system this
enables.

The XTR200's internals are themselves the de-facto standard current-transmitter
architecture --- a two-op-amp, sense-resistor-feedback voltage-to-current
converter: an input amplifier servos the control voltage across a precision set
resistor, and a second amplifier with an integrated PMOS pass transistor
reproduces the resulting current at the output. An early revision of this
design implemented the same topology discretely with a precision dual op amp
(OPA2192) per channel. The integrated part displaced it on three grounds that
compound at 64 channels: (i) its transfer function is set by internally trimmed
thin-film resistors, so the transconductance is uniform across channels and
calibration collapses to a single per-channel offset-current reading
(Section~\ref{sec:validation}), whereas a discrete channel's gain inherits the
tolerance of its external resistors and would require a two-parameter fit on
every channel; (ii) its 47\,G$\Omega$ output impedance renders the source
effectively ideal, leaving the sense divider's known 120\,k$\Omega$ shunt as
the only load-dependent error --- which is what permits the analytic
correction in the measurement model below; and (iii) the output stage,
short-circuit protection, and active-low output-disable pin (used here for
power-up sequencing of the per-board front-end enables) arrive integrated,
where a discrete channel would add a pass transistor, protection network, and
enable gating per channel --- board area that would break the
eight-channels-per-daughterboard density.
\note{verify the exact datasheet numbers + wording against the XTR200
datasheet before submission.}

\subsection{Architecture}
A single RP2040 (Raspberry Pi Pico) controller drives up to eight identical
daughterboards. Each daughterboard carries one \textbf{DAC80508} (8-ch,
write-only), one \textbf{AD7193} (8-ch ADC), eight \textbf{XTR200} current
sources, and its own \textbf{REF5030} 3.0\,V precision reference shared by that
board's DAC and ADC --- the basis of the per-board ratiometric accuracy
argument (Section~\ref{sec:context}). Addressing uses two 74HC138 3-to-8
decoders (one per ADC/DAC bank)
for chip-select, and one SN74LV595 shift register to gate each board's analog
front ends.

\begin{itemize}[nosep]
  \item \textbf{SPI0} (shared): AD7193 ADCs + the SN74LV595 front-end enable
        register. Mode 3, 1\,MHz.
  \item \textbf{SPI1} (write-only): DAC80508 bus.
  \item \textbf{Addressing}: shared address lines select daughterboard $k$ via
        the inverted decoder mapping (address $= 8-k$); one bank enable
        (ADC\_EN / DAC\_EN) is asserted at a time.
\end{itemize}

\todo{Pull the full subsystem prose from CLAUDE.md: HC138 selector, AD7193
continuous-scan readout, DAC80508 external-reference/gain setup, XTR595
active-low front-end enable. This is mostly transcription + figures.}

\subsection{Measurement model}
The reported voltage is the raw ADC-pin voltage. The true load voltage is
recovered with the 6:1 sense divider: $V_\text{heater} = V_\text{ADC}\times 6$.
The divider (100\,k$\Omega$ + 20\,k$\Omega$ = 120\,k$\Omega$) draws a small,
\emph{known} current from the load node, corrected analytically:
\[
  I_\text{heater} = I_\text{source} - \frac{V_\text{heater}}{120\,\text{k}\Omega}.
\]
This correction is exact and computed from the live measurement (not a
calibrated parameter). The XTR200 transconductance ($\approx 0.47$\,V/mA seed)
and a per-channel offset current ($I_{OS}$) are captured by the calibration in
Section~\ref{sec:validation}. The $\times6$ relation above holds above a
low-signal knee at $V_\text{node}\approx44$\,mV, below which the sense path
departs from it; the measured transfer function, the additive correction that
applies above the knee, and the resulting bound on the usable low end are
given in Section~\ref{sec:vsense-linearity}.

% =====================================================================
\section{Design files summary}
\label{sec:design-files}
\todo{Fill once files are archived to Zenodo. Every released file gets a row.}

\renewcommand{\arraystretch}{1.25}
\noindent\begin{tabularx}{\textwidth}{@{}L{3.4cm} L{2.6cm} L{3.0cm} X@{}}
\toprule
\textbf{Design file name} & \textbf{File type} & \textbf{Open source license} & \textbf{Location of the file} \\
\midrule
Controller board (schematic + PCB) & KiCad / Gerber & CERN-OHL-S v2 & \todo{repo link} \\
Daughterboard (schematic + PCB) & KiCad / Gerber & CERN-OHL-S v2 & \todo{repo link} \\
Firmware (\texttt{src/}, \texttt{include/}) & C++ (PlatformIO) & MIT & \todo{repo link} \\
Host GUI (\texttt{koi\_gui.py}) & Python & MIT & \todo{repo link} \\
Calibration / sweep tooling & Python & MIT & \todo{repo link} \\
Bill of materials & CSV / XLSX & CC-BY-4.0 & \todo{repo link} \\
\bottomrule
\end{tabularx}
\renewcommand{\arraystretch}{1.0}

% =====================================================================
\section{Bill of materials summary}
\label{sec:bom}
\todo{Add unit costs, quantities (note per-board vs per-system), suppliers, and
part numbers. Provide the full itemised BOM as a supplementary CSV; summarise
the major line items here.}
\todo{State the assembly method and its cost explicitly --- the DAC80508 and
AD7193 are fine-pitch packages, so say whether the reference build is hand
reflow (stencil + hot plate/oven) or a PCBA service, and include assembly in
the system cost either way. HardwareX judges reproducibility by whether a
typical lab can actually build it.}

\renewcommand{\arraystretch}{1.2}
{\small
\setlength{\tabcolsep}{4pt}
\noindent\begin{longtable}{@{}L{3.4cm} c L{1.3cm} L{1.3cm} L{1.7cm} L{2.5cm} L{2.5cm}@{}}
\toprule
\textbf{Designator / component} & \textbf{Qty} & \textbf{Unit cost (USD)} & \textbf{Total cost (USD)} & \textbf{Supplier} & \textbf{Supplier Part No.} & \textbf{Manufacturer Part No.} \\
\midrule
\endhead
Raspberry Pi Pico (RP2040) controller & 1 & \todo{} & \todo{} & \todo{} & \todo{} & \todo{} \\
DAC80508 (8-ch DAC) & 8 & \todo{} & \todo{} & \todo{} & \todo{} & \todo{} \\
AD7193 (8-ch 24-bit ADC) & 8 & \todo{} & \todo{} & \todo{} & \todo{} & \todo{} \\
XTR200 current source & 64 & \todo{} & \todo{} & \todo{} & \todo{} & \todo{} \\
74HC138 decoder & 2 & \todo{} & \todo{} & \todo{} & \todo{} & \todo{} \\
SN74LV595 shift register & \todo{} & \todo{} & \todo{} & \todo{} & \todo{} & \todo{} \\
REF5030 3.0\,V precision voltage reference (one per daughterboard) & 8 & \todo{} & \todo{} & \todo{} & \todo{} & \todo{} \\
Sense divider resistors (100\,k/20\,k) & \todo{} & \todo{} & \todo{} & \todo{} & \todo{} & \todo{} \\
Passives, connectors, stacking headers (consolidated) & --- & --- & \todo{} & \todo{} & --- & --- \\
PCBs (controller + 8 daughterboards) & 9 & \todo{} & \todo{} & \todo{} & \todo{} & \todo{} \\
PCB assembly (fine-pitch reflow / PCBA service) & 9 & \todo{} & \todo{} & \todo{} & --- & --- \\
\midrule
\multicolumn{3}{r}{\textbf{System total}} & \todo{} & & & \\
\bottomrule
\end{longtable}}
\renewcommand{\arraystretch}{1.0}

\noindent{\small\color{red} Placeholder values --- table will be updated with
final quantities, unit costs, and supplier/manufacturer part numbers from the
released BOM spreadsheet.}

% =====================================================================
\section{Build instructions}
\label{sec:build}
\todo{Step-by-step assembly with photos: PCB fabrication notes (production uses
ENIG finish --- HASL test boards oxidise and intermittently fail detection),
population order, stacking the daughterboards, reference connections. Then
firmware flashing:}
\begin{verbatim}
pio run -t upload      # build + flash the RP2040 over USB
pio device monitor     # serial console @ 115200
\end{verbatim}

% =====================================================================
\section{Operation instructions}
\label{sec:operation}

The firmware runs a line-based ASCII command server over USB serial (115200,
\texttt{\textbackslash n}-terminated). Each command returns exactly one reply
line. Channels use a flat global index $g = \text{board}\times 8 +
\text{channel}$ (0--63); unpopulated channels report \texttt{nan}. Populated
boards are auto-detected at boot. Every \texttt{OK} reply echoes its command
name so the host can confirm a reply belongs to the command it sent, and every
firmware-initiated line begins with \texttt{\#} (boot banner, calibration
progress, \texttt{STREAM} dumps, diagnostics), so an unprefixed line is always a
direct command reply.

\renewcommand{\arraystretch}{1.2}
\noindent\begin{tabularx}{\textwidth}{@{}L{3.2cm} X L{4.2cm}@{}}
\toprule
\textbf{Command} & \textbf{Effect} & \textbf{Reply} \\
\midrule
\texttt{*IDN?}            & identify & \texttt{KOI,8x8,fw1.1} \\
\texttt{*RST}             & all currents 0, front-ends disabled & \texttt{OK *RST} \\
\texttt{ISETA i0 \dots i63} & set all 64 currents (mA, $g$-order) & \texttt{OK ISETA} \\
\texttt{ISET g mA}        & set one channel & \texttt{OK ISET <g>} \\
\texttt{MEASA? [mask]}    & measure all 64 (or masked boards) & \texttt{v0,\dots,v63} \\
\texttt{MEAS? g}          & measure one channel & \texttt{<volts>} \\
\texttt{XTR enmask}       & bit $b=1\to$ board $b$ front-ends enabled & \texttt{OK XTR 0x..} \\
\texttt{AVG n}            & on-micro averages per measurement (1--64) & \texttt{OK AVG <n>} \\
\texttt{RATE fs}          & AD7193 filter word (speed/noise) & \texttt{OK RATE <fs>} \\
\texttt{STREAM ON|OFF}    & periodic \texttt{\#} dump for monitoring & \texttt{OK STREAM ON|OFF} \\
\texttt{RESCAN}           & re-detect boards at runtime & \texttt{OK RESCAN active=0x.. new=0x..} \\
\texttt{PING? b}          & board liveness (ADC ID + one conversion) & \texttt{OK PING <b> 1|0} \\
\bottomrule
\end{tabularx}
\renewcommand{\arraystretch}{1.0}

\medskip
A typical experiment loop is \texttt{ISETA \dots} (set), settle, \texttt{MEASA?}
(read). A Tkinter host GUI (\texttt{koi\_gui.py}) polls \texttt{MEASA?} and
displays raw and divider-corrected voltage for all 64 channels in an 8$\times$8
grid; \texttt{sweep\_ch0.py} performs a scripted single-channel current sweep.

% =====================================================================
\section{Validation and characterization}
\label{sec:validation}
\note{This is the critical section for review. Plan: calibrate every channel
against a Keithley 2400 over 0.25--6 mA, then report the figures below.}

\subsection{Calibration method}
\label{sec:cal-method}

\paragraph{Bench setup.}
Every channel is terminated in a known load resistor standing in for the TiN
heater: a thin-film 1\,k$\Omega$ part with $\le$25--50\,ppm/K temperature
coefficient in a large package (to bound self-heating: 36\,mW at 6\,mA), whose
value is taken from an in-situ four-wire measurement rather than from the part
grade. A dedicated calibration jig PCB carries all 64 loads, permanently
connected so that every channel remains loaded and driven throughout the
campaign. Each load carries Kelvin taps at its resistor pads --- a sense pair
and a force pair --- and a 23-channel bank of four-pole relay stages (paired DPDT signal relays)
connects one load's taps at a time to a 6.5-digit DMM (Keithley~2100),
operated in offset-compensated four-wire mode for resistance scans so that
any constant residual current through the load cancels; a re-positionable
sense-only harness maps the relay bank onto each third of the array in turn,
without ever interrupting a drive path. The same taps thus serve two
functions: four-wire resistance measurement of every load through the jig
itself (repeatable at any time, e.g.\ warm, to bound drift), and Kelvin
voltage sensing during the current sweeps, so every sweep point yields the
load voltage directly and the channel current as
\[
  I = \frac{V_\text{DMM}}{R_\text{meas}} + \frac{V_\text{DMM}}{120\,\text{k}\Omega},
\]
the second term being the known sense-divider current
(Section~\ref{sec:description}). Because the DMM is switched across the loads
in parallel --- never inserted in series --- the current path is never broken:
all 64 channels remain loaded and driven throughout the scan, i.e.\ the device
is characterized under representative operating conditions rather than one
channel at a time into an otherwise idle board. Mechanical relays are used
(open-contact leakage in the pA range) so the jig itself cannot contribute at
the microampere level being resolved. A metal-foil transfer-standard resistor
and a Keithley 2400 source-measure unit inserted in series on a small number of
channels provide an independent cross-check of the voltage-over-resistance
method. The jig design files (schematic, PCB, control script) are released
with the paper. \todo{instrument list with calibration status; uncertainty
budget table (DMM V, load R tolerance/TCR/self-heating, divider term $\to$
total $I$ uncertainty) vs.\ the $\pm4\,\mu$A $I_{OS}$ being resolved.}

\paragraph{Sweep protocol and fit.}
Each channel is swept over 0.25--6\,mA in both directions --- the linear
operating regime; sub-100\,$\mu$A points are excluded because the source
cannot sink current, so readings near zero bottom out rather than extrapolate
linearly. A per-channel linear fit of commanded versus measured current yields
\texttt{calSlope} (the transconductance, expected $\approx$0.47\,V/mA and
shared across channels, consistent with the trimmed-thin-film argument of
Section~\ref{sec:description}) and \texttt{calOffset} (the per-part offset
current $I_{OS}$, approximately equal to the enabled zero-command reading).
The calibration proper therefore uses \emph{only} the 1\,k$\Omega$ loads; many
sweep points serve to verify linearity and average noise, not to fit
additional parameters.

\paragraph{Separating current-side from voltage-side errors.}
A single-load sweep, however many points it contains, carries a structural
confound: with a fixed load, $V = IR$ is perfectly correlated with $I$, so an
error term that scales with \emph{current} (XTR200 gain error, true $I_{OS}$,
DAC error) is indistinguishable from one that scales with \emph{voltage}
(board leakage, the $V/120\,\text{k}\Omega$ divider correction, ADC or divider
gain error) --- both produce identical residuals. To break the correlation,
one board is re-run with its loads exchanged for $\sim$300\,$\Omega$ and
$\sim$2\,k$\Omega$ parts of the same grade: at the same 3\,mA setpoint the
load then sees $\sim$0.9, $\sim$3, and $\sim$6\,V across the three load sets
--- the same current at a $\sim$7$\times$ span of voltage. Comparing the
apparent per-channel offset across the three loads attributes it: an offset
that is invariant with load is genuinely current-side (real $I_{OS}$, and
belongs in \texttt{calOffset}), whereas one that scales with $V$ is
voltage-side (leakage or divider-correction error) and must \emph{not} be
folded into \texttt{calOffset} --- doing so would be correct only at the
calibration load and would mis-correct on a real heater of different
resistance. The same re-run validates the analytic divider correction
directly, exercises a wider portion of the ADC span, and yields a
load-independence figure for the source. This is an attribution measurement,
not a three-point calibration: if it confirms the error budget is
current-side, the remaining seven boards need only the 1\,k$\Omega$ dataset.

\subsection{Current-mode characterization}
\label{sec:current-char}
The current-drive characterization mirrors the per-parameter methodology of a
representative commercial module (Qontrol Q8a~\cite{qontrol_q8a}) so the two can
be compared plot-for-plot; all figures below report \emph{Koi}'s own measured
data. Note the differing operating ranges (Koi 0--6\,mA vs.\ Q8a 0--100\,mA), so
resolution/precision are additionally reported as a fraction of full scale.
\emph{Preliminary bench data (single board, 2026-06-17):} XTR200 gain is
near-ideal (datasheet span error $\le \pm0.065\%$, nonlinearity $\pm0.003\%$),
so \texttt{calSlope} is treated as a shared constant; the per-channel offset
$I_{OS}$ is the term needing measurement, bench-measured $\approx\pm4\,\mu$A
(datasheet $\pm10\,\mu$A max).

\paragraph{Measured drive accuracy (channel 0, 2026-07-30).} A 64-point sweep
spanning 0.1--6.383\,mA was taken with a Keithley 2100 across a
996.4\,$\Omega$ four-wire-measured load, in \emph{randomized} setpoint order so
that any residual drift appears as scatter rather than as an apparent gain
error. The actual sourced current is recovered as
$I=V_\text{DMM}/R + V_\text{DMM}/120\,\text{k}\Omega$ (load plus the sense
divider's share). Against commanded current,
\[
  I_\text{actual} = 1.00319\,I_\text{cmd} + 2.43\,\mu\text{A}.
\]
That is a $+0.319\,\%$ \emph{gain} error and an $I_{OS}$ of $+2.43\,\mu$A, well
within the datasheet $\pm10\,\mu$A. Uncalibrated, the worst deviation across the
range is $22.7\,\mu$A. The \emph{linearity} residual after removing gain and
offset is $0.070\,\mu$A rms, i.e.\ $0.0011\,\%$ of the 6.383\,mA full scale ---
a $320\times$ reduction for a two-parameter fit. The source is therefore
excellent and essentially all of the drive error is a single uncalibrated scale
factor, confirming the shared-slope / per-channel-offset model above. No
compliance limit was reached, with the XTR200 \textsc{errorflag} clear
throughout.

\note{The load resistance is the most leveraged constant in this section: it
converts every measured voltage into a current, so an error in it presents as a
gain error and nothing else. An earlier campaign assumed 1005.68\,$\Omega$ for
this same load against a correct four-wire value of 996.4\,$\Omega$, and that
$0.92\,\%$ difference was enough to reverse the \emph{sign} of the reported gain
error. Every raw meter voltage is archived with the released data so that R
enters only at analysis time.}
\todo{Repeat across all 64 channels to publish the per-channel $I_{OS}$
distribution; the above is one channel.}
\note{RESOLVED --- the uniform $-24\,\mu$A static offset seen on an early
devkit sweep (all channels, boards 0--2) was never a current-side term. It is
\emph{measurement}-side: the sense path's low-signal gain deficit
(Section~\ref{sec:vsense-linearity}) presents above the knee as a fixed
$-3.75$\,mV ADC-referred error, which divided by the load reads back as an
apparently uniform current offset --- hence its being uniform across parts and
far above the datasheet $I_{OS}$ maximum. Per-channel $I_{OS}$ numbers taken
after correcting the sense path are therefore trustworthy; the drive side never
had this error.}

% --- Current transfer function (coarse + fine) ---
\begin{figure}[htbp]
  \centering
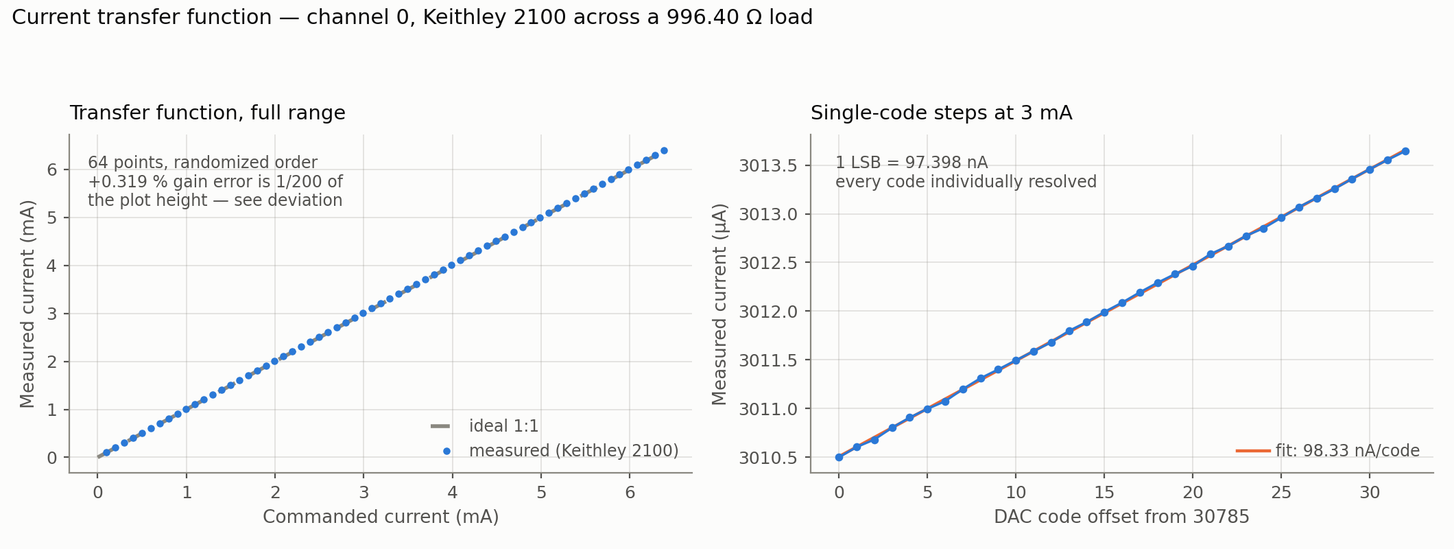
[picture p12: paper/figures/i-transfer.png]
  
  \caption{Current transfer function, channel~0. Left: commanded current vs.\
  current measured by the external reference over the full 0--6.383\,mA range,
  64 points in randomized order; the $+0.319\,\%$ gain error is far too small to
  see at this scale, which is why the deviation plot of
  Figure~\ref{fig:i-deviation} is the informative view. Right: the single-code
  region at 3\,mA, showing that individual DAC codes ($1\,\text{LSB}=97.4$\,nA)
  are cleanly resolved by the reference.}
  \label{fig:i-transfer}
\end{figure}

% --- Current deviation: ext DMM + onboard ADC ---
\begin{figure}[htbp]
  \centering
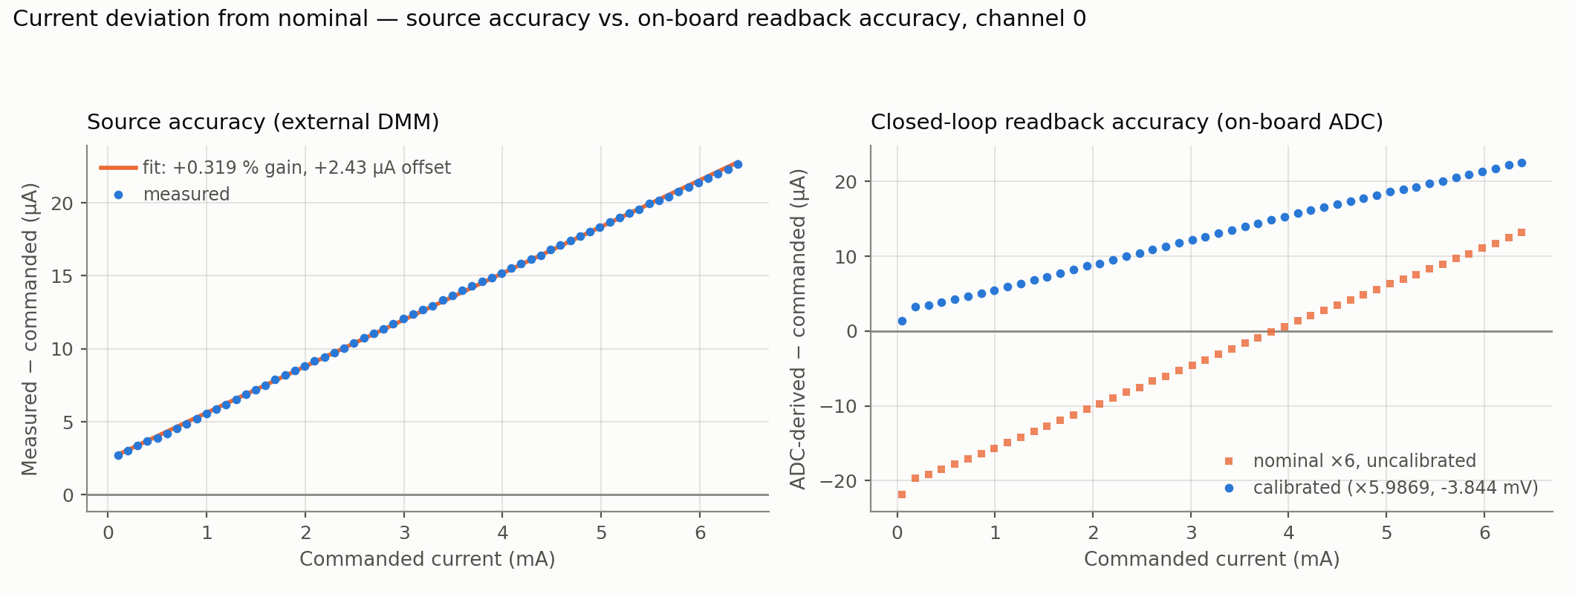
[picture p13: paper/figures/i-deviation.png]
  
  \caption{Current deviation from nominal, channel~0. Left: against the external
  reference DMM --- source accuracy. The entire error is one straight line, i.e.\
  a gain term plus an offset, with $0.070\,\mu$A rms left over. Right: against
  the on-board AD7193 readback --- closed-loop measurement accuracy, after the
  sense-divider correction, shown both with the nominal $\times6$ divider ratio
  and after the two-parameter sense calibration of
  Section~\ref{sec:vsense-linearity}.}
  \label{fig:i-deviation}
\end{figure}

\paragraph{Code-level resolution and linearity.} Resolution was measured with
the external DMM alone --- the on-board ADC takes no part --- by stepping the
DAC one code at a time and deriving current from the voltage across the
four-wire load. The DAC is 16-bit over the 0--6.3830\,mA span, so the
instrument offers \textbf{65\,536 individually settable currents per channel},
on each of the 64 channels independently, with
\[
  1\,\text{LSB} = 97.398\,\text{nA} = 97.03\,\mu\text{V across }996.4\,\Omega .
\]
The 2100's own noise over the same reads is $\approx$8\,$\mu$V, i.e.\ $0.08$\,LSB,
so the reference resolves roughly twelve steps within a single DAC code and
\emph{every code is individually resolvable}; the DAC's LSB, not the
measurement, sets the resolution. Points taken: 64 across the full range in
randomized order, plus 33-code ($\pm16$\,LSB) sweeps centred on 1.0, 3.0 and
5.0\,mA. Because a $\pm16$-code span is short enough that the converter's own
integral nonlinearity dominates its local slope, the mean step measured that way
($98.9$\,nA) characterizes \emph{step uniformity}, not gain; the gain figure is
the full-range fit above.

\medskip
\noindent\begin{tabular}{@{}llr@{}}
\toprule
\textbf{Quantity} & \textbf{Measured} & \textbf{As \% FS} \\
\midrule
Settable levels & 65\,536 per channel (1\,LSB $=97.398$\,nA) & --- \\
INL (randomized order) & rms 0.64\,LSB, max $-1.31$\,LSB & $0.0020\,\%$ \\
INL (monotonic order) & rms 0.60\,LSB, max $-1.51$\,LSB & $0.0023\,\%$ \\
DNL & max $0.40$\,LSB & --- \\
Monotonicity & 0 non-monotonic steps in 96 & --- \\
Effective resolution & 15.6 of 16 bits & --- \\
\bottomrule
\end{tabular}
\medskip

The converter is monotonic everywhere measured, at every centre and every
settling time tried.

\paragraph{Load self-heating, and why it no longer confounds the INL.} Measuring
INL on a resistive load is not straightforward, because code order and thermal
state are confounded: a monotonic 0--6.38\,mA ramp raises dissipation from 0 to
40\,mW across the sweep, and a metal-film resistor at $\sim$50\,ppm/$^\circ$C
warming a few degrees drifts $\sim$250\,ppm --- comparable to the
$\sim$0.002\,\% FS being resolved. In an earlier configuration of this bench,
with the load convecting freely, a monotonic ramp returned an INL some 60\,\%
larger than a randomized sweep of the same converter, the difference being
entirely thermal.

The measurements reported here remove that mechanism at its source: the load is
held at ambient by forced air, so its dissipation no longer maps onto code order.
Two independent controls confirm it rather than assume it. First, the codes are
still visited in random order with a fixed reference point re-measured every
fourth point and each datum corrected by the reference interpolated to its
timestamp. Second --- and this is the decisive one --- the same 48 codes were
also swept \emph{monotonically}, the worst case for a self-heating artifact. The
two agree: \textbf{rms 0.64\,LSB randomized against 0.60\,LSB monotonic}, well
inside the 0.09\,LSB per-code repeatability. A thermal term large enough to
matter cannot survive that comparison, so the residual is genuine converter
nonlinearity.

The practical consequence for anyone reproducing this work is that randomized
order is a cheap check rather than a requirement, provided the load is
temperature-stabilized; without stabilization it is mandatory, and a monotonic
ramp will overstate INL substantially.

\begin{figure}[htbp]
  \centering
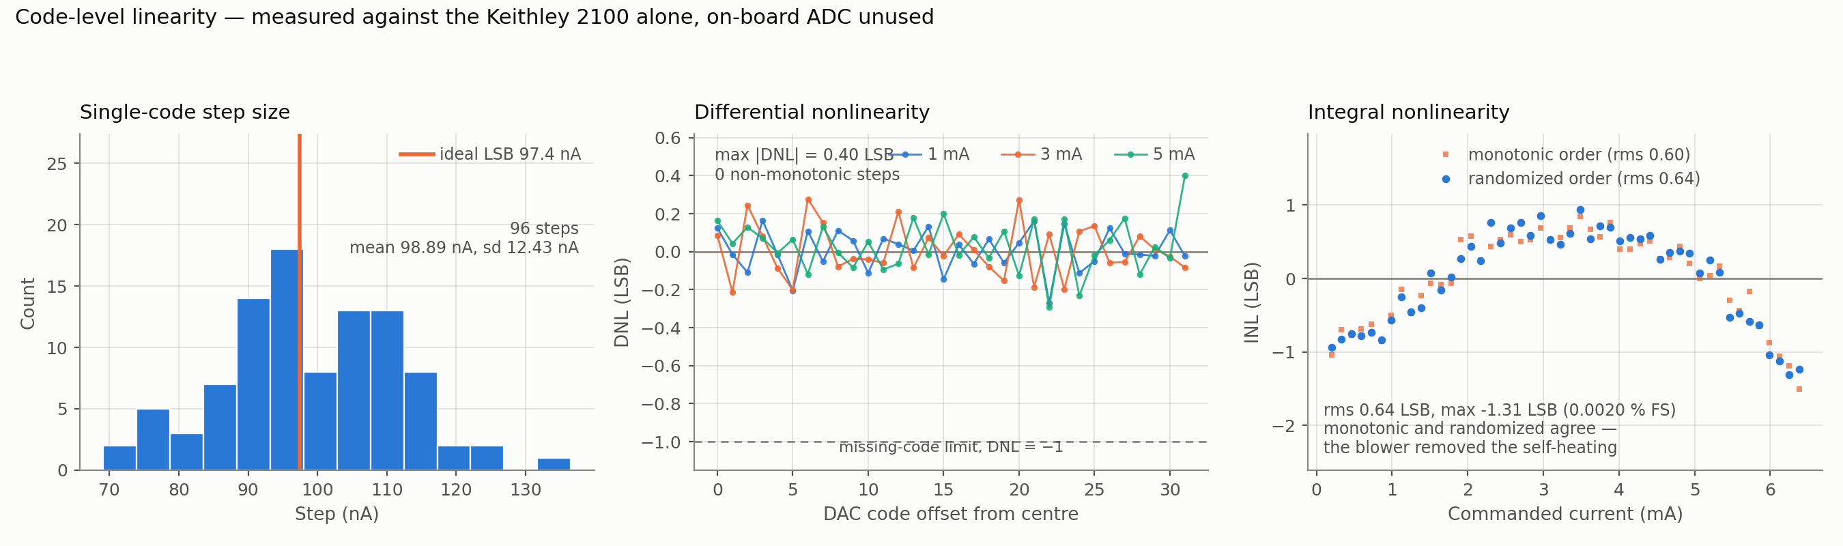
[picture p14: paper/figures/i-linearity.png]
  
  \caption{Code-level linearity, channel~0, measured against the external DMM
  with the on-board ADC unused. Left: single-code step-size distribution
  (1\,LSB $=97.4$\,nA over the 0--6.383\,mA span). Centre: current-mode
  differential nonlinearity, max $0.40$\,LSB, with no step approaching the
  $-1$\,LSB missing-code limit at any of the three centres. Right: integral
  nonlinearity in randomized and in monotonic code order. With the load held at
  ambient by forced air the two agree (rms 0.64 vs.\ 0.60\,LSB), which is the
  evidence that load self-heating no longer contaminates the measurement.}
  \label{fig:i-linearity}
\end{figure}

% --- Precision / std dev ---
\begin{figure}[htbp]
  \centering
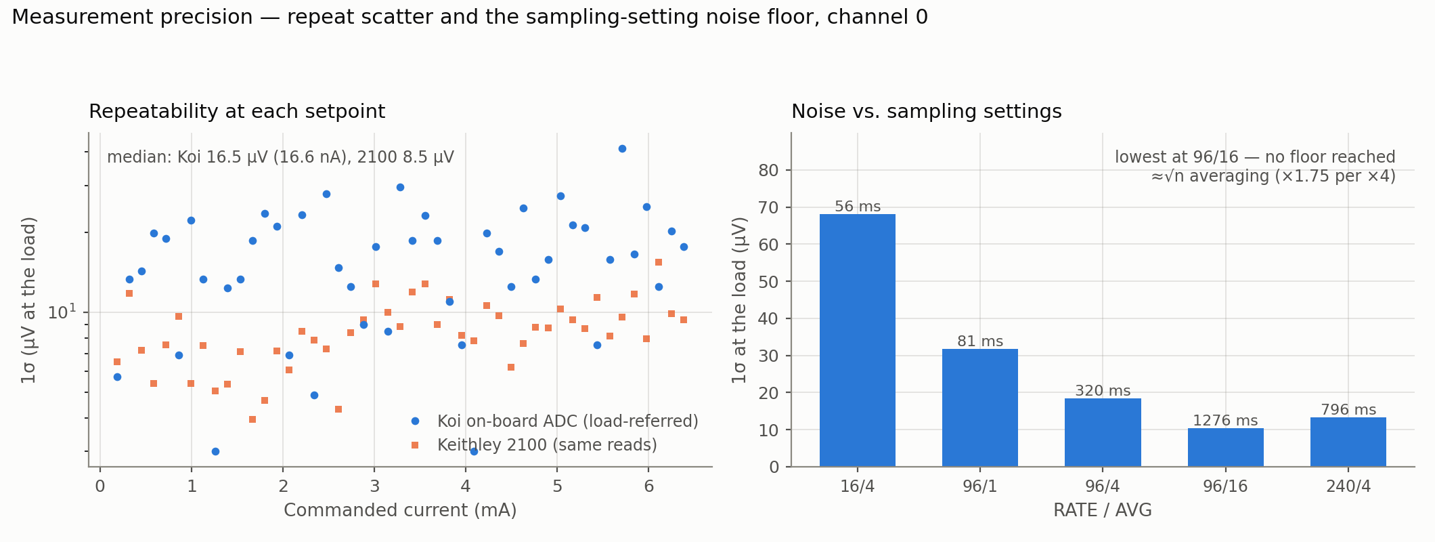
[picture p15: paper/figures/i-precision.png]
  
  \caption{Measurement precision, channel~0. Left: $1\sigma$ over repeated reads
  at each setpoint across the operating range, for the on-board ADC
  (load-referred) and for the reference DMM over the same reads. Right: noise
  against the two sampling controls, annotated with the per-read cost. Noise
  falls monotonically as $\sqrt{n}$ with averaging over the whole range tested,
  so no floor is reached; the choice of setting is a speed/noise trade rather
  than a search for a floor (Section~\ref{sec:noise}).}
  \label{fig:i-precision}
\end{figure}

\subsection{Sense-divider correction and end-to-end resistance accuracy}
\label{sec:divider-correction}
The divider-current correction
$I_\text{heater}=I_\text{source}-V_\text{heater}/120\,\text{k}\Omega$ was
validated end-to-end by comparing the resistance the instrument reports against
the four-wire value of the reference load (996.4\,$\Omega$). Resistance is
computed from the calibrated sense model of Section~\ref{sec:vsense-linearity},
the commanded current, and the divider correction:

\medskip
\noindent\begin{tabular}{@{}lrr@{}}
\toprule
\textbf{Range} & \textbf{$R$ reported} & \textbf{vs.\ four-wire} \\
\midrule
$I\ge0.5$\,mA & $1000.65\pm0.80\,\Omega$ & $+0.426\,\%$ \\
$I\ge1.0$\,mA & $1000.44\pm0.45\,\Omega$ & $+0.406\,\%$ \\
$I\ge2.0$\,mA & $1000.27\pm0.24\,\Omega$ & $+0.389\,\%$ \\
\bottomrule
\end{tabular}
\medskip

The $+0.4\,\%$ bias is \emph{not} a failure of the divider correction: it is the
$+0.319\,\%$ drive gain error of Section~\ref{sec:current-char} propagating
through, because $R$ is computed from \emph{commanded} rather than measured
current. The quantity that characterizes the instrument is the scatter,
$\pm0.24$--$0.45\,\Omega$ ($0.02$--$0.05\,\%$), which is what remains once
\texttt{calSlope} is trimmed. Correspondingly, the resistance accuracy of an
uncalibrated unit is set by the drive scale factor, and of a calibrated unit by
the sense residual (Section~\ref{sec:vsense-linearity}) and the drive linearity
($0.0011\,\%$ FS).
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

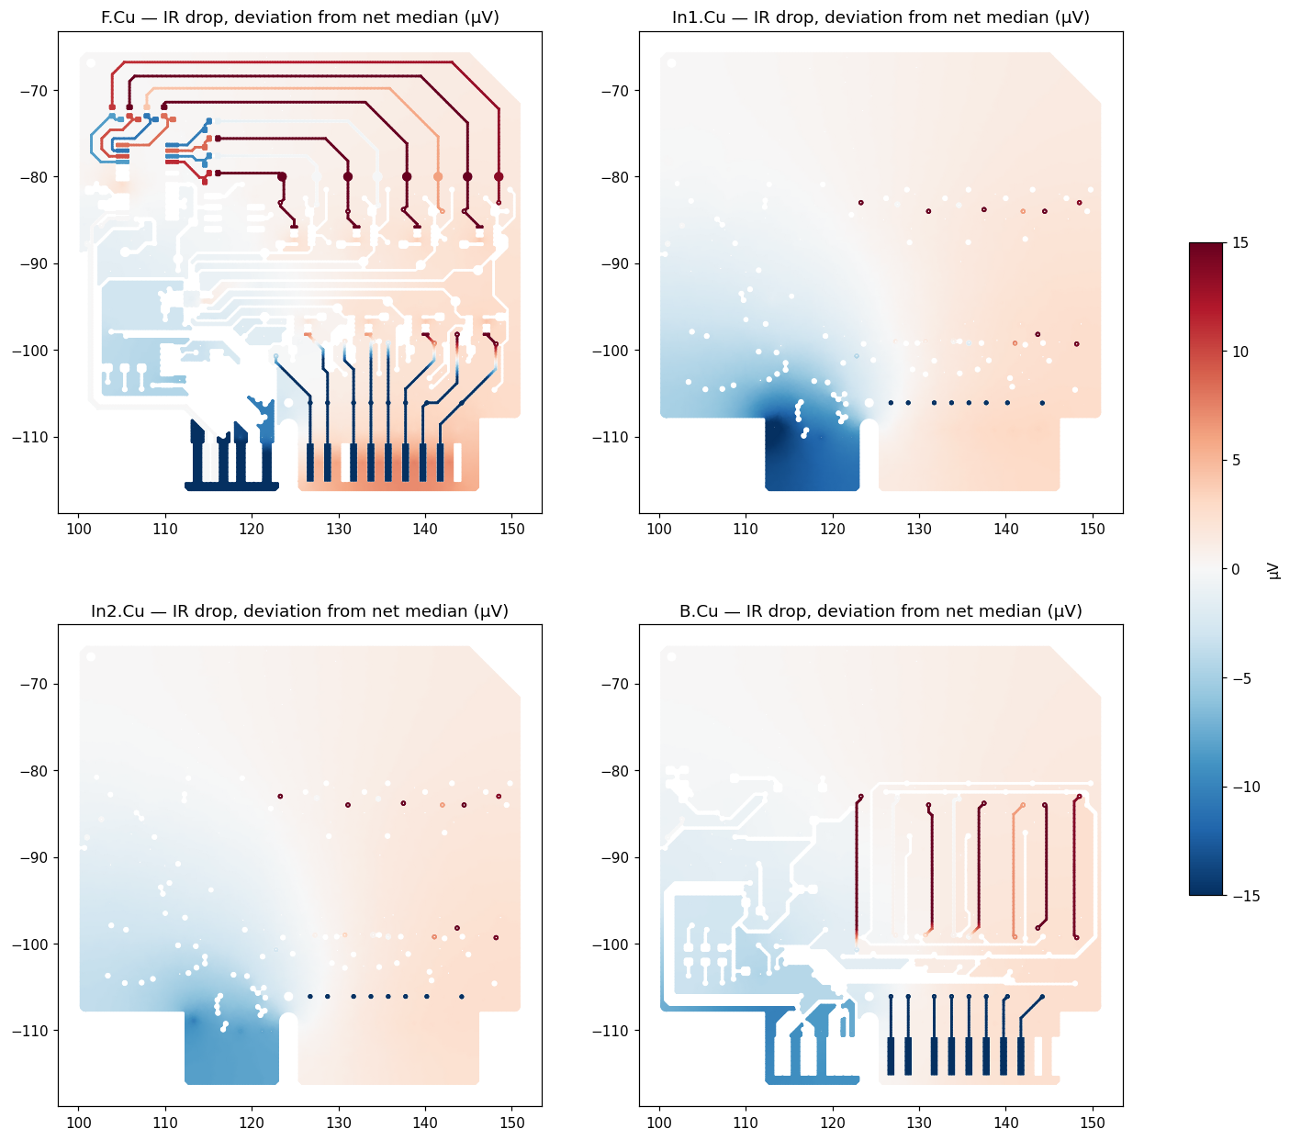
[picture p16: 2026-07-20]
report/figures/ir_drop_voltage.png

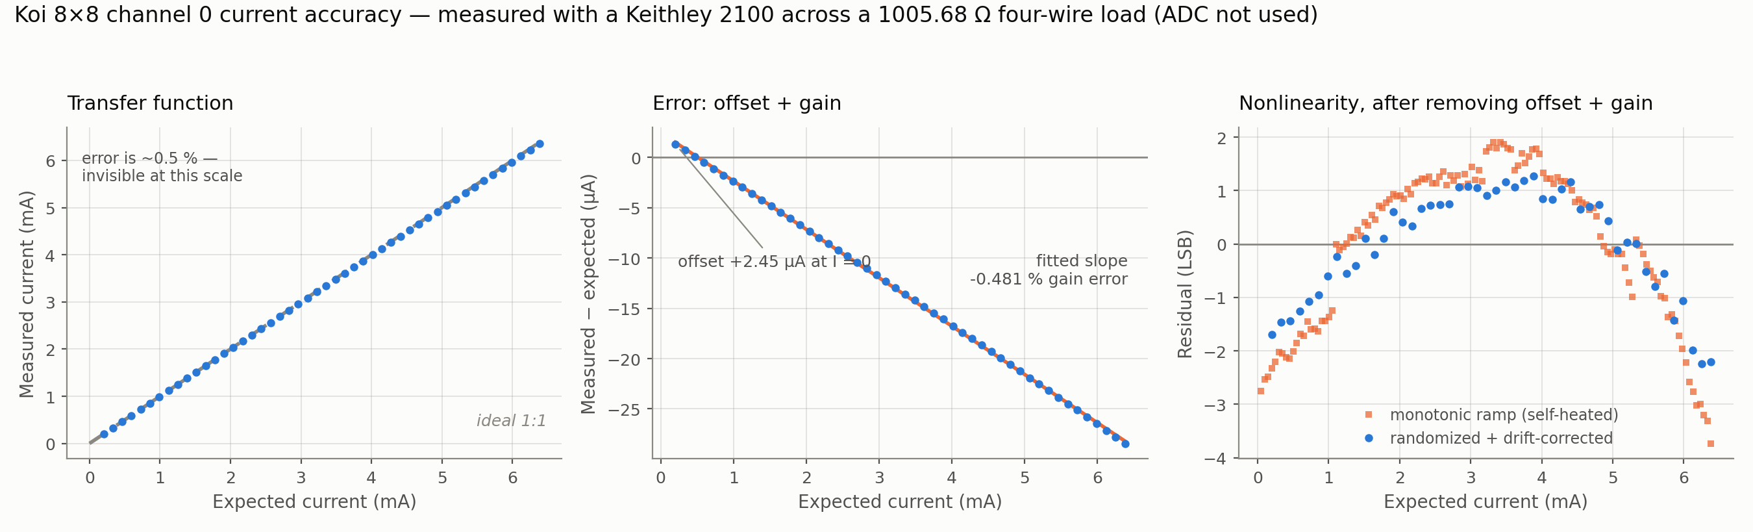
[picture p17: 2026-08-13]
paper/figures/current-accuracy.png

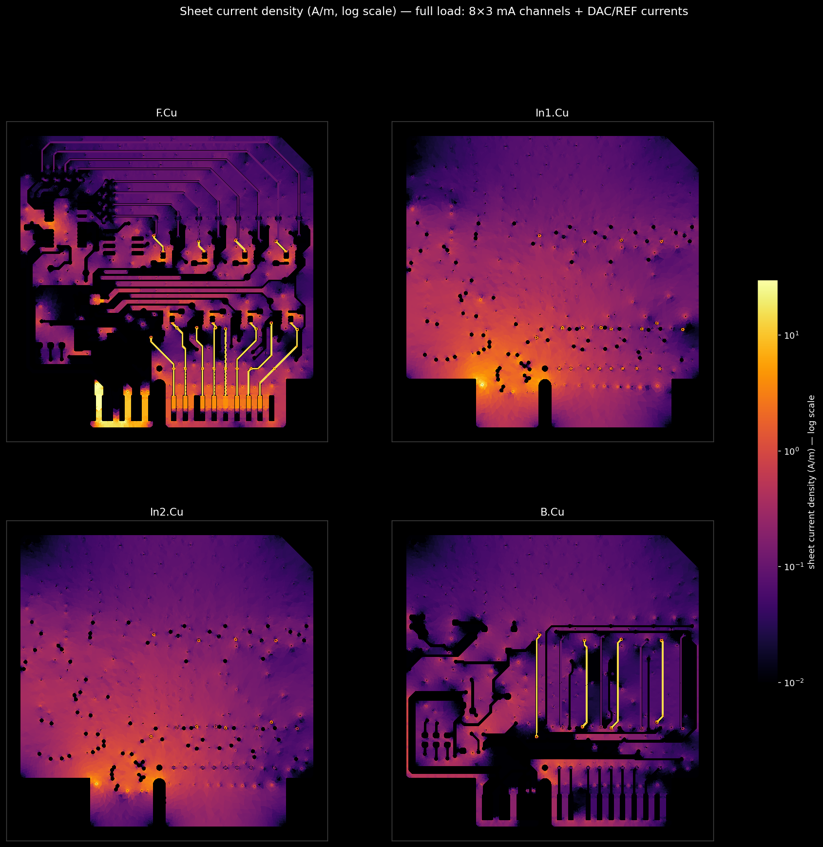
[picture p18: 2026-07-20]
report/figures/current_density.png

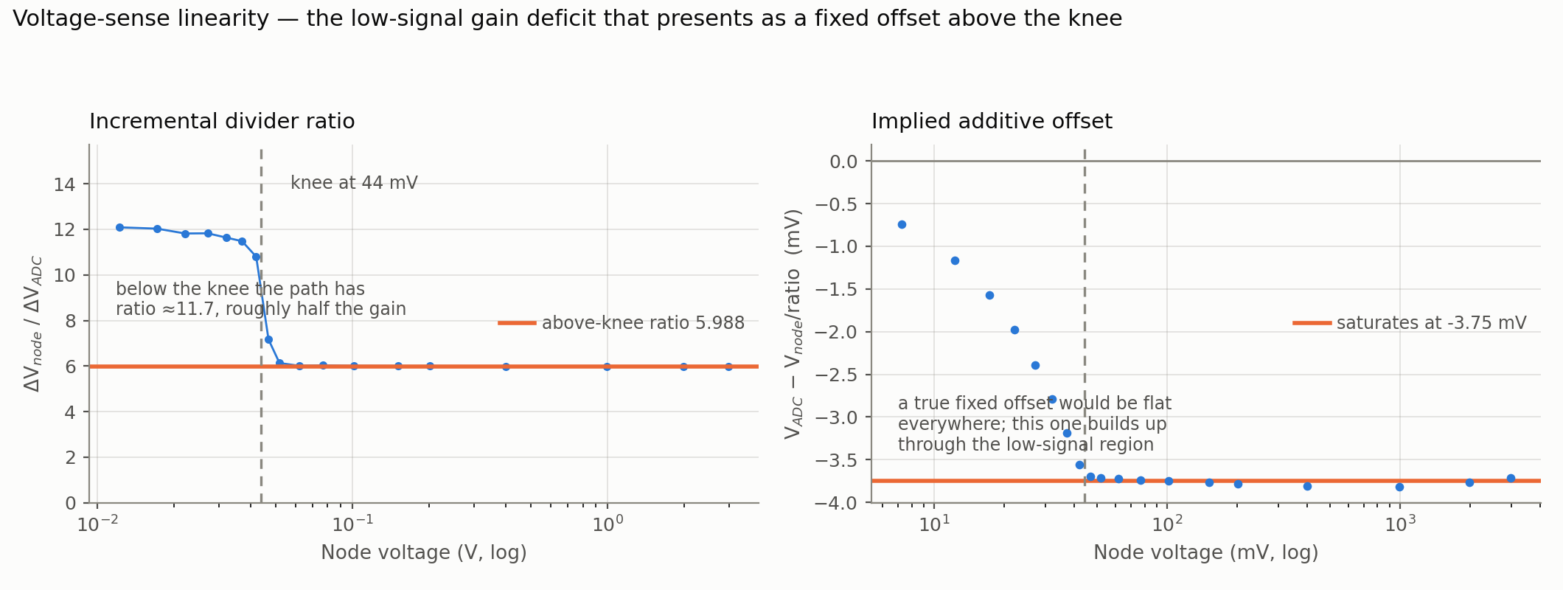
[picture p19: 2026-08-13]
paper/figures/v-sense.png

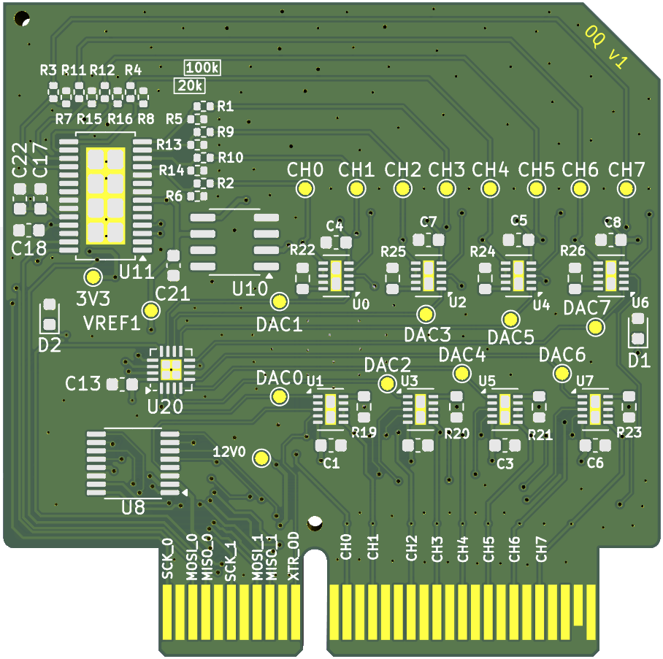
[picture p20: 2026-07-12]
hardware/daughterboard/version 1/daughterboard_top_transparent.png

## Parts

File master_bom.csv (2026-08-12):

Section | Designators (per board) | Description | Value / Part | Package | Qty per board | Qty system | Unit price USD | Ext price USD | Notes
Daughterboard (x8) | U0-U7 | Precision current-source front end | XTR200 | WSON-10 2x3mm | 8 | 64 | 1.456 | 93.18 | 66 ordered (64 populated + 2 spares); spares add $2.91
Daughterboard (x8) | U11 | 24-bit sigma-delta ADC (8-ch readout) | AD7193 | TSSOP-28 | 1 | 8 | 18.13 | 145.04
Daughterboard (x8) | U20 | 16-bit 8-ch DAC | DAC80508Z | WQFN-16 3x3mm | 1 | 8 | 15.50 | 124.00
Daughterboard (x8) | U10 | 3.0 V precision voltage reference | REF5030EIDR | SOIC-8 | 1 | 8 | 6.00 | 48.00 | One per board; shared by that board's DAC + ADC (no 9th ref on controller)
Daughterboard (x8) | U8 | Parallel-load 8-bit shift register | SN74LV165ADBR | TSSOP-16 | 1 | 8 | 0.461 | 3.69 | Mouser 595-SN74LV165ADBR (cut tape)
Daughterboard (x8) | R19-R26 | Per-channel precision resistor (0.1% thin film) | 4.7k (RS PRO RSTNF03BTC4701) | 0603 | 8 | 64 | 0.067 | 4.28 | RS part (0.646 kr); schematic value now correctly reads 4.7k
Daughterboard (x8) | R1-R4, R9-R12, R17 | Sense divider top (6:1) + jellybean | 100k | 0603 | 9 | 72 | TBD |  | 2026-07-27 revision: footprint changed 0402->0603, merging the priced RS 0402 divider group with the jellybean R17; old RS 243-0436 part no longer matches footprint, needs requote
Daughterboard (x8) | R5-R8, R13-R16 | Sense divider bottom (6:1) 0.1% thin film | 20k | 0603 | 8 | 64 | TBD |  | 2026-07-27 revision: footprint changed 0402->0603; old RS TRSTNF02BTCY2002 part no longer matches footprint, needs requote
Daughterboard (x8) | R18 | 1-Wire bus pull-up (new, pairs with U9) | 2.7k | 0603 | 1 | 8 | TBD |  | New 2026-07-27: added alongside U9 AT21CS01, likely pull-up for its 1-Wire DATA line - confirm purpose/part
Daughterboard (x8) | R27 | Resistor | 1.5 | 0603 | 1 | 8 | TBD |  | Jellybean passive
Daughterboard (x8) | C1-C8, C10, C12, C14-C15, C17-C22, C24 | Decoupling capacitor MLCC 50V | 100nF (Wurth 885012206095R) | 0603 | 19 | 152 | 0.045 | 6.84 | RS 257-1100 (0.431 kr); C24 added 2026-07-27
Daughterboard (x8) | C11, C13, C16, C23 | Capacitor MLCC 50V 10% | 1uF (RS PRO RSMC03KTB500105) | 0603 | 4 | 32 | 0.047 | 1.51 | RS 271-0969 (0.457 kr)
Daughterboard (x8) | C9, C25 | Bulk capacitor | 10uF | 0603 | 2 | 16 | TBD |  | See capacitor allowance note; C25 added 2026-07-27
Daughterboard (x8) | D1 | Indicator LED | LED | 0603 | 1 | 8 | TBD |  | 2026-07-27 revision: D2/D3 removed, only D1 remains
Daughterboard (x8) | U9 | 1-Wire board-ID EEPROM (new) | AT21CS01 | SOT-23 | 1 | 8 | TBD |  | New 2026-07-27; likely board/channel identification - confirm part choice and BOM description
Daughterboard (x8) | L1 | AD7193 DVDD filter ferrite (with R27 10R) | 600R@100MHz (TAI-TECH FCM1608KF-601T05) | 0603 | 1 | 8 | 0.0105 | 0.08 | Was Sunlord GZ1608U601CTF (C96708) - delisted at LCSC, JLC 'No Match Found'. LCSC C133937, quoted 2026-08-11. Same 600R@100MHz; 500 mA rating is ample - L1 carries only AD7193 DVDD through R27
Daughterboard (x8) | J1 | Card-edge connector (PCIe x4 pattern) | Custom_PCIe_x4 | card edge | 1 | 8 | 0.00 | 0.00 | Edge fingers on the PCB itself - no component cost
Daughterboard (x8) | 19x test points | Test point pads | TestPoint | pad | 19 | 152 | 0.00 | 0.00 | Bare pads - no component cost
Motherboard (x1) | A1 | Controller | Raspberry Pi Pico (RP2040) | SMD module | 1 | 1 | 7.00 | 7.00
Motherboard (x1) | U1, U5 | 3-to-8 decoder (ADC / DAC chip select) | SN74HC138PWR | TSSOP-16 | 2 | 2 | 0.49 | 0.98 | 2026-08 rework: was SN74LV138 in SSOP-16; price carried over from that line. LCSC C157527
Motherboard (x1) | U2 | 8:1 analog multiplexer | TMUX1208PW | TSSOP-16 | 1 | 1 | 0.70 | 0.70 | New 2026-08. LCSC C494728. ESTIMATE - unquoted; TI/DigiKey class $0.60-0.80
Motherboard (x1) | U3 | Shift register (XTR front-end enables) | SN74LV595 | TSSOP-16 | 1 | 1 | 1.00 | 1.00
Motherboard (x1) | J1-J8 | PCIe x4 socket (daughterboard slots) | Samtec PCIE-064-02-F-D-TH | through-hole | 8 | 8 | 2.29 | 18.32 | DigiKey SAM9742-ND; $2.29 @ qty 1-49 (breaks: $1.864 @ 50, $1.582 @ 100). LCSC C4597619
Motherboard (x1) | J9-J11 | 50-pin FFC connector (channel outputs) | Molex 54132-5033 | 0.5 mm horizontal | 3 | 3 | 3.00 | 9.00 | todo.txt flags ambiguity: $3 each (=$9) or $3 total - confirm. Largest single uncertainty on this board (+/-$6)
Motherboard (x1) | J12 | DC barrel jack with switch pin | Barrel_Jack | through-hole | 1 | 1 | 1.00 | 1.00 | Sole power source; input range 9-15 V (was 12 V nominal) - see hardware/motherboard/POWER.md. LCSC C84007
Motherboard (x1) | F1 | Input overcurrent protection (PPTC) | Littelfuse 1812L150/24MR | 1812 | 1 | 1 | 0.047 | 0.05 | New 2026-08 power rework. LCSC C142805 ($0.0474)
Motherboard (x1) | D2 | Input TVS clamp | SMBJ16A | SMB | 1 | 1 | 0.1333 | 0.13 | New 2026-08 power rework; SMBJ16A replaces SMBJ13A (13 V standoff conducts continuously on a 15 V rail). Littelfuse, LCSC C151254, quoted 2026-08-11
Motherboard (x1) | D6 | Q1 gate-source zener clamp | BZT52C18 | SOD-123 | 1 | 1 | 0.0322 | 0.03 | New 2026-08 power rework. Diodes Inc BZT52C18-7-F, LCSC C192739, quoted 2026-08-11. 18 V: above the 15 V rail, below Q1's +/-20 V Vgs
Motherboard (x1) | C10 | +12V sense divider filter | 100nF 50V X7R | 0603 | 1 | 1 | 0.0077 | 0.01 | New 2026-08. LCSC C14663, same part as C1-C4. Sits at the Pico ADC pin, not at the divider
Motherboard (x1) | R5, R10 | +12V sense divider (100k / 22k) | 100k + 22k | 0805 | 2 | 2 | 0.01 | 0.02 | New 2026-08. LCSC C96346 / C114565. Ratio 22/122 = 0.1803 into GPIO26/ADC0
Motherboard (x1) | Q1 | Reverse-polarity protection P-FET | AO3407A | SOT-23 | 1 | 1 | 0.04 | 0.04 | New 2026-08 power rework. LCSC C15155. ESTIMATE - unquoted
Motherboard (x1) | U6 | 5 V switching regulator | K7805-500R3 | THT SIP-3 | 1 | 1 | 0.4970 | 0.50 | New 2026-08 power rework; replaces PS1. LCSC C19188491 (EVISUN, $0.4970); genuine MORNSUN C86735 costs more
Motherboard (x1) | U4 | 3.3 V LDO (logic rail + daughterboard +3V3) | LP5912-3.3DRV | WSON-6 2x2mm | 1 | 1 | 0.34 | 0.34 | New 2026-08 power rework. LCSC C524780 ($0.3409)
Motherboard (x1) | D1 | Schottky feeding Pico VSYS from +5V | SS34 | SMA | 1 | 1 | 0.02 | 0.02 | New 2026-08 power rework. LCSC C8678
Motherboard (x1) | R7, R8 | 3V3_EN interlock divider (10k / 4.7k) | 10k + 4.7k | 0805 | 2 | 2 | 0.01 | 0.02 | New 2026-08: makes the Pico a subsystem of the board rather than USB-startable - see POWER.md. LCSC C84376 / C60816
Motherboard (x1) | R1, R6 | Pull-up | 100k | 0805 | 2 | 2 | 0.01 | 0.02 | LCSC C96346. ESTIMATE - jellybean passive
Motherboard (x1) | C1-C4 | Decoupling capacitor MLCC 50V | 100nF (Wurth 885012206095R) | 0603 | 4 | 4 | 0.045 | 0.18 | Same RS part as daughterboard decoupling; C4 added 2026-08. LCSC C14663
Motherboard (x1) | C5 | Switcher input bulk | 10uF | 1210 | 1 | 1 | 0.05 | 0.05 | New 2026-08 power rework. LCSC C77102. ESTIMATE - unquoted
Motherboard (x1) | C6 | Switcher output bulk | 22uF | 0805 | 1 | 1 | 0.05 | 0.05 | New 2026-08 power rework. LCSC C45783. ESTIMATE - unquoted
Motherboard (x1) | C7 | Input bulk electrolytic | 220uF | CP_Elec 8x10 | 1 | 1 | 0.15 | 0.15 | New 2026-08 power rework. LCSC C125981. ESTIMATE - unquoted
Motherboard (x1) | C8, C9 | LDO in/out capacitor | 10uF | 0805 | 2 | 2 | 0.03 | 0.06 | New 2026-08 power rework. LCSC C84416. ESTIMATE - unquoted
PCB fabrication |  | Daughterboard PCB (analog) | daughterboard | 4-layer | 1 | 8 | 30.00 | 240.00
PCB fabrication |  | Motherboard PCB | motherboard |  | 1 | 1 | 3.00 | 3.00
Assembly |  | PCB assembly |  |  |  |  | TBD |  | Not yet quoted (todo.txt: TBA)
TOTAL |  |  |  |  |  |  |  | 709.29 | Sum of priced lines (populated qty) = $11.08/channel. RS passive prices converted at 1 SEK = 0.1035 USD (Jul 2026), assumed ex-VAT. 2026-08 motherboard power rework: PS1 (XP Power DSM2-12-S3-S, $10.37) deleted, protection chain + K7805 + LP5912 added for $2.06 (+$0.05 for the added C4), so the board fell $47.80 -> $39.54 and the system $717.34 -> $709.08. 2026-08-11: D2 requoted SMBJ13A -> SMBJ16A ($0.06 -> $0.1333, Littelfuse C151254), D6 gate clamp ($0.0322), C10 sense filter ($0.0077) and R5/R10 sense divider ($0.02) added, system $709.08 -> $709.21. Daughterboard L1 ferrite requoted C96708 -> C133937 ($0.08 for 8, was TBD/unpriced), system -> $709.29. Motherboard LCSC codes are taken from the schematic's own LCSC symbol field. Motherboard lines marked ESTIMATE total $1.07 and are unquoted (U2 mux, P-FET, bulk caps, 0805 pull-ups) - the TVS is now quoted. TBD items outstanding: assembly, 10uF caps, 100k/20k 0603 dividers (72+64 units, needs requote after 0402->0603 footprint change), 1.5R, LEDs, ferrite, R18 pull-up, U9 EEPROM

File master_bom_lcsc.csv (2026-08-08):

Section | Designators (per board) | Description | Value / Part | Package | Qty per board | Qty system | Unit price USD | Ext price USD | Notes | LCSC part no | LCSC MPN | LCSC package | LCSC stock | LCSC unit price USD | LCSC ext price USD | LCSC notes
Daughterboard (x8) | U0-U7 | Precision current-source front end | XTR200 | WSON-10 2x3mm | 8 | 64 | 1.456 | 93.18 | 66 ordered (64 populated + 2 spares); spares add $2.91 | NOT STOCKED | XTR200DQCR | WSON-10 (2x3) | 0 |  |  | LCSC does not carry XTR200 (only XTR111/115/116/117). Buy from TI/DigiKey/Mouser. Keep the existing $1.456 line.
Daughterboard (x8) | U11 | 24-bit sigma-delta ADC (8-ch readout) | AD7193 | TSSOP-28 | 1 | 8 | 18.13 | 145.04 |  | C125128 | AD7193BRUZ-REEL | TSSOP-28 | 43 | 16.0835 | 128.67 | Tier 1+; 10+ = $15.4444, 30+ = $13.9237, 100+ = $12.9592. Only 43 in stock -> buy the 8 in one go. Saves $16.37 vs current BOM.
Daughterboard (x8) | U20 | 16-bit 8-ch DAC | DAC80508Z | WQFN-16 3x3mm | 1 | 8 | 15.50 | 124.00 |  | C2679499 | DAC80508ZRTER | WQFN-16-EP(3x3) | 156 | 16.0553 | 128.44 | DECIDED 2026-07-30: next board spin uses the ZR variant (this part), not the current ZCRTER. *** SCHEMATIC CHANGE REQUIRED: pin 15 is SDO on ZR, not CLR - it must no longer be tied high (an output shorted to VDD). Optionally route it to a Pico GPIO to make the DAC bus readable. Tiers: 10+ $15.3359, 30+ $14.0917, 100+ $13.0046.
Daughterboard (x8) | U10 | 3.0 V precision voltage reference | REF5030EIDR | SOIC-8 | 1 | 8 | 6.00 | 48.00 | One per board; shared by that board's DAC + ADC (no 9th ref on controller) | C69362 | REF5030AIDR | SOIC-8 | 484 | 1.1536 | 9.23 | *** BIG SAVING: $38.77 vs the $6.00 BOM line. Grade check: LCSC has the A grade (+/-0.1% initial, 8 ppm/C max). BOM says 'REF5030EIDR' which is not a TI suffix - confirm whether you need the tighter I grade. Tiers: 10+ $0.9284, 100+ $0.6756.
Daughterboard (x8) | U8 | Parallel-load 8-bit shift register | SN74LV165ADBR | TSSOP-16 | 1 | 8 | 0.461 | 3.69 | Mouser 595-SN74LV165ADBR (cut tape) | C201716 | SN74LV165APWR | TSSOP-16 | 860 | 0.3604 | 2.88 | BOM MPN says ADBR = SSOP-16 but the package column says TSSOP-16; LCSC's PWR is the TSSOP-16 part, which matches the footprint. MOQ 5. Tiers: 50+ $0.2825, 150+ $0.2491.
Daughterboard (x8) | R19-R26 | Per-channel precision resistor (0.1% thin film) | 4.7k (RS PRO RSTNF03BTC4701) | 0603 | 8 | 64 | 0.067 | 4.28 | RS part (0.646 kr); schematic value now correctly reads 4.7k | C855887 | AT0603BRD074K7L | 0603 | OUT OF STOCK | 0.0804 | 5.15 | YAGEO AT series (+/-0.1%, 25 ppm/C) - LCSC lists it under 'Pre-ordered RLCs' and the product page reports out of stock; lead time applies. LCSC does NOT carry RT0603BRD074K7L. RS part is cheaper and in stock - consider keeping RS for this line.
Daughterboard (x8) | R1-R4, R9-R12, R17 | Sense divider top (6:1) + jellybean | 100k | 0603 | 9 | 72 | TBD |  | 2026-07-27 revision: footprint changed 0402->0603, merging the priced RS 0402 divider group with the jellybean R17; old RS 243-0436 part no longer matches footprint, needs requote | C122538 | RT0603BRD07100KL | 0603 | 631520 | 0.0336 | 2.42 | RESOLVES A TBD. YAGEO RT, +/-0.1%, 25 ppm/C, 100 mW, 75 V. Deep stock. Tiers: 200+ $0.0288, 600+ $0.0267. R17 (jellybean) could use a 1% part instead but at 3.4c it is not worth a second line item.
Daughterboard (x8) | R5-R8, R13-R16 | Sense divider bottom (6:1) 0.1% thin film | 20k | 0603 | 8 | 64 | TBD |  | 2026-07-27 revision: footprint changed 0402->0603; old RS TRSTNF02BTCY2002 part no longer matches footprint, needs requote | C723637 | RT0603BRD0720KL | 0603 | OUT OF STOCK | 0.0316 | 2.02 | RESOLVES A TBD (price) but *** OUT OF STOCK at LCSC. Same RT series/tolerance as the 100k so the divider stays matched (both +/-0.1%, 25 ppm/C) - worth waiting for or second-sourcing rather than mixing series. Tiers: 200+ $0.0259, 600+ $0.0234.
Daughterboard (x8) | R18 | 1-Wire bus pull-up (new, pairs with U9) | 2.7k | 0603 | 1 | 8 | TBD |  | New 2026-07-27: added alongside U9 AT21CS01, likely pull-up for its 1-Wire DATA line - confirm purpose/part | C13167 | 0603WAF2701T5E | 0603 | OUT OF STOCK | 0.0029 | 0.29 | RESOLVES A TBD. UNI-ROYAL thick film +/-1%, 100 mW. MOQ 100 so you buy 100 for $0.29. Out of stock at LCSC but this is a commodity value - any 2.7k 1% 0603 works.
Daughterboard (x8) | R27 | Resistor | 10 | 0603 | 1 | 8 | TBD |  | VALUE CHANGED 1.5 -> 10 ohm 2026-07-30: DVDD filter corner 97 kHz -> 14 kHz for 4.2 mV drop. Schematic + padne directive updated 2026-07-30; PCB still needs Update PCB from Schematic to pick up the value and the LCSC field. | C144117 | AF0603JR-0710RL | 0603 |  |  |  | RESOLVES A TBD. YAGEO 10 ohm +/-5% 100mW +/-100ppm/C 0603, JLCPCB EXTENDED part. Neither tolerance nor TCR matters here: +/-5% moves the 14.0 kHz corner to 13.3-14.7 kHz, and power is 1.6 uW into a 100 mW part. Alternative C22859 (UNI-ROYAL 0603WAF100JT5E, +/-1%, Basic) is equivalent electrically and would avoid a JLCPCB setup fee. Unit price not captured - commodity, expect <$0.01/pc. WARNING when substituting: 0603WAF1000T5E (C22775) is 100 ohm and 0603WAF1501T5E (C22843) is 1.5k - 'R' is the decimal point, all-numeric codes are digits+multiplier.
Daughterboard (x8) | U13-U16 | Per-channel sense buffer, 2 ch per package | OPA2333 | VSON-8 3x3mm | 4 | 32 | TBD |  | NEW 2026-08-04: unity-gain followers between the 6:1 divider tap and the AD7193 AIN pins, one half per channel. Removes the AD7193 buffered-input bias-current x 16.7k source-impedance term. Was entirely absent from this BOM until now. | TBD |  | VSON-8 |  |  |  | *** LCSC PART NOT RESOLVED - needs a lookup before ordering. The schematic value reads 'OPA2333xxDRB', which is the KiCad symbol name, not an orderable MPN. DRB = VSON-8 (3x3), matching the placed footprint (8 pins + exposed pad tied to GND, correct since GND is V- here). Real orderable is OPA2333AIDRBR (reel) / -T (tape). Confirm LCSC actually stocks the DRB package - the DGK (VSSOP-8) and D (SOIC-8) variants are far more commonly stocked and switching to either would require a footprint change. NOT PRICED, so excluded from both totals below.
Daughterboard (x8) | R28-R35 | AIN anti-alias series resistor (post-buffer) | 1k | 0603 | 8 | 64 | TBD |  | NEW 2026-08-04 with the OPA2333 buffer stage. VALUE CHANGED 100 -> 1k 2026-08-04: paired with 100nF this puts the AIN anti-alias corner at 1.59 kHz (was 339 kHz at 100R/4.7nF, which gave no attenuation at either the OPA333 chop or the AD7193 modulator rate). Schematic + PCB value fields updated 2026-08-04. | TBD |  | 0603 |  |  |  | *** LCSC PART NOT RESOLVED - do not order from this row. These parts previously carried C154077, which is WRONG: C154077 is the 20k used by R5-R8/R13-R16 (see production/bom.csv), inherited by copy-paste when the symbols were created. The field has been cleared rather than guessed. Tolerance and TCR are irrelevant here - no DC current flows into the AD7193's GOhm buffered input except nA-class bias, so any 1k 0603 works and a 1% jellybean is fine. Candidates to look up: YAGEO RC0603FR-071KL, or UNI-ROYAL 0603WAF1001T5E per the code scheme documented on the R27 row. Expect <$0.01/pc. NOT PRICED, so excluded from both totals below.
Daughterboard (x8) | C1-C10, C12, C14-C15, C17-C22, C24, C26-C33 | Decoupling capacitor MLCC 50V + AIN anti-alias caps | 100nF (Wurth 885012206095R) | 0603 | 28 | 224 | 0.045 | 10.08 | RS 257-1100 (0.431 kr); C24 added 2026-07-27; C9 ADDED 2026-07-30 - it is 0.1uF (C14663) on VREF, was wrongly grouped with the 10uF bulk line; C26-C33 ADDED 2026-08-04 - the per-channel AIN filter caps, value changed 4.7nF -> 100nF so they fold onto this reel instead of needing a new line item | C14663 | CC0603KRX7R9BB104 | 0603 | 1723600 | 0.0242 | 5.42 | YAGEO 100nF 50V X7R +/-10% - same spec as the Wurth part. MOQ 50. Saves $3.16. Tiers: 500+ $0.0203, 1500+ $0.0186 (224 units is still under the 500 break, so 0.0242 holds). Qty corrected 19->20/board (152->160) when C9 was moved here from the 10uF line, then 20->28/board (160->224) when C26-C33 joined 2026-08-04. X7R is correct for C26-C33 despite being a signal-path filter: the OPA333 drives that node continuously and the AD7193 runs BUF=1, so the cap never has to slew or recover from mux kickback - dielectric absorption has no settling tail to distort, and the voltage coefficient only shifts the corner, it does not create a DC error. 100nF C0G does not exist in 0603 anyway (same reason C17/C18 went X7R).
Daughterboard (x8) | C11, C13, C16, C23 | Capacitor MLCC 50V 10% | 1uF (RS PRO RSMC03KTB500105) | 0603 | 4 | 32 | 0.047 | 1.51 | RS 271-0969 (0.457 kr) | C15849 | CL10A105KB8NNNC | 0603 | 5650 | 0.0155 | 0.78 | Samsung 1uF 50V +/-10% - note X5R not X7R. MOQ 50 (you need 32, so buy 50 = $0.78). C23 MOVED from +3.3V to VDDA 2026-07-30 - it is now the dominant capacitance on the AD7193 DVDD filter output (1 uF + C18 0.1 uF = 1.1 uF), so this X5R part governs that node while the schematic note says X7R for C17/C18. Electrically fine (-55~+85 C, small bias derating at 3.3 V); reconcile the wording or requote in X7R.
Daughterboard (x8) | C25 | Bulk capacitor | 10uF | 0603 | 1 | 8 | TBD |  | See capacitor allowance note; C25 added 2026-07-27. C9 REMOVED from this line 2026-07-30 - C9 is 0.1uF, not 10uF; it now sits on the 100nF line. Qty corrected 2->1/board (16->8). | C96446 | CL10A106MA8NRNC | 0603 | 510340 | 0.0921 | 0.74 | RESOLVES A TBD. Samsung 10uF 25V X5R +/-20%. MOQ 20 (need 8, buy 20). C25 is the +12V bulk feeding the 8 XTR200 VSP pins. DC bias derating at 12 V is ACCEPTED DELIBERATELY: ~2-3 uF effective, still 3-4x the combined C1-C8. Rail needs little - 48 mA max (8 ch x 6 mA) into high-PSRR current sources. Do NOT substitute tantalum. X5R = -55~+85 C; recheck if thermal validation shows >85 C near C25.
Daughterboard (x8) | D1 | Indicator LED | LED | 0603 | 1 | 8 | TBD |  | 2026-07-27 revision: D2/D3 removed only D1 remains | C2286 | KT-0603R | 0603 | 4978400 | 0.0075 | 0.75 | RESOLVES A TBD. Red 0603, Vf 1.8-2.4 V @ 20 mA, 300 mcd. MOQ 100 -> $0.75 for the lot.
Daughterboard (x8) | U9 | 1-Wire board-ID EEPROM (new) | AT21CS01 | SOT-23 | 1 | 8 | TBD |  | New 2026-07-27; likely board/channel identification - confirm part choice and BOM description | C616192 | AT21CS01-STUM10-T | SOT-23-3 | 2660 | 0.5694 | 4.56 | RESOLVES A TBD. Microchip 1-Kbit single-wire EEPROM with factory 64-bit serial - exactly the board-ID use case. Alt: C6747066 (AT21CS01-TOHM10-B). Tiers: 10+ $0.451, 100+ $0.3374.
Daughterboard (x8) | L1 | Ferrite bead 600R @ 100 MHz | FerriteBead | 0603 | 1 | 8 | TBD |  | The old '1.5 A' spec was a phantom - it came from the KiCad symbol name FerriteBead_0603_1.5A, not the design. L1 feeds only the AD7193 DVDD pin: 0.4 mA (datasheet DIDD at 3 V, internal oscillator - no crystal fitted). Any 0603 bead is >100x the needed current. | C96708 | GZ1608U601CTF | 0603 |  |  |  | RESOLVES A TBD. Sunlord 600 ohm @ 100 MHz, 380 mohm DCR, 500 mA, +/-25%, -55~+125 C. JLCPCB EXTENDED part (setup fee applies if using JLCPCB assembly; C1002 GZ1608D601TF is the Basic equivalent, 450 mohm / 200 mA). Unit price not captured - previous candidate C141723 was $0.0118. Damping check: with R27=10 ohm and 1.1 uF on VDDA, Q=0.09, no LC peaking.
Daughterboard (x8) | J1 | Card-edge connector (PCIe x4 pattern) | Custom_PCIe_x4 | card edge | 1 | 8 | 0.00 | 0.00 | Edge fingers on the PCB itself - no component cost | N/A |  |  |  | 0.00 | 0.00 | PCB feature - nothing to source.
Daughterboard (x8) | 19x test points | Test point pads | TestPoint | pad | 19 | 152 | 0.00 | 0.00 | Bare pads - no component cost | N/A |  |  |  | 0.00 | 0.00 | PCB feature - nothing to source.
Motherboard (x1) | A1 | Controller | Raspberry Pi Pico (RP2040) | SMD module | 1 | 1 | 7.00 | 7.00 |  | C7203002 | Raspberry Pi Pico | module |  |  |  | Listed in the JLCPCB parts library (C7203002) but the LCSC retail product page 404s - it appears to be assembly-only stock, not shippable as a loose part. Keep the $7.00 retail line. (Bare RP2040 chip is C2040 if the design is ever respun.)
Motherboard (x1) | U1, U5 | 3-to-8 decoder (ADC / DAC chip select) | SN74LV138 (74HC138) | SSOP-16 | 2 | 2 | 0.49 | 0.98 |  | C485077 | SN74LVC138APWR | TSSOP-16 | 1717 | 0.7553 | 1.51 | *** SUBSTITUTION: the LV part (C388843, SN74LV138APW) is listed but 'not available now' with no price. LVC is the in-stock alternative - 1.65-3.6 V, fine at 3.3 V, faster, but check VIH/VIL against the Pico's drive. Also note both LCSC options are TSSOP-16 while the BOM package column says SSOP-16. LCSC is MORE expensive here than the current $0.49 line.
Motherboard (x1) | U3 | Shift register (XTR front-end enables) | SN74LV595 | TSSOP-16 | 1 | 1 | 1.00 | 1.00 |  | C116847 | SN74LV595APWR | TSSOP-16 | 14545 | 0.3747 | 1.87 | Exact match for the firmware's SN74LV595. MOQ 5 -> $1.87 for 5 pcs (spares included). Unit price is 63% below the current BOM line.
Motherboard (x1) | J1-J8 | PCIe x4 socket (daughterboard slots) | Samtec PCIE-064-02-F-D-TH | through-hole | 8 | 8 | 2.29 | 18.32 | DigiKey SAM9742-ND; $2.29 @ qty 1-49 (breaks: $1.864 @ 50, $1.582 @ 100) | C4597619 | PCIE-064-02-F-D-TH | through-hole | 1 | 1.6292 | 13.03 | Exact MPN match and 29% cheaper than DigiKey, but *** ONLY 1 IN STOCK - you need 8. Treat the $13.03 as best-case. Right-angle sibling C4571870 (PCIE-064-02-F-D-RA) has 5 in stock at $7.08 - wrong orientation and 4x the price.
Motherboard (x1) | J9-J11 | 50-pin FFC connector (channel outputs) | Molex 54132-5033 | 0.5 mm horizontal | 3 | 3 | 3.00 | 9.00 | todo.txt flags ambiguity: $3 each (=$9) or $3 total - confirm | NOT STOCKED | 54132-5033 | 0.5mm | 0 |  |  | *** Not at LCSC, and Molex lists 54132-5033 as OBSOLETE. This needs a replacement part regardless of distributor - re-select a current 50-pos 0.5 mm horizontal FFC/FPC ZIF connector.
Motherboard (x1) | J12 | DC barrel jack with switch pin | Barrel_Jack | through-hole | 1 | 1 | 1.00 | 1.00 |  | C111567 | DC005-T20 | through-hole R/A | 21105 | 0.2207 | 1.10 | 3-pin DC005 (has the switch contact), 2.0 mm centre pin, 3 A / 12 V, right-angle THT. MOQ 5 -> $1.10 for 5. Confirm the 2.0 mm pin matches your PSU barrel (2.1 mm variants: C319099 / C381116).
Motherboard (x1) | PS1 | Isolated DC-DC converter 12 V | XP Power DSM2-12-S3-S | THT | 1 | 1 | 10.37 | 10.37 |  | NOT STOCKED | DSM2-12-S3-S | SIP THT | 0 |  |  | *** Not at LCSC. Also: DigiKey attributes DSM2-12-S3-S to CUI Inc, not XP Power - the BOM manufacturer looks wrong. (12 V in, 3.3 V / 606 mA isolated out.)
Motherboard (x1) | C1-C3 | Decoupling capacitor MLCC 50V | 100nF (Wurth 885012206095R) | 0603 | 3 | 3 | 0.045 | 0.13 | Same RS part as daughterboard decoupling | C14663 | CC0603KRX7R9BB104 | 0603 | 1723600 | 0.0242 | 0.07 | Same reel as the daughterboard decoupling line - order once.
PCB fabrication |  | Daughterboard PCB (analog) | daughterboard | 4-layer | 1 | 8 | 30.00 | 240.00 |  | N/A |  |  |  |  |  | Not an LCSC catalogue item (JLCPCB / your fab).
PCB fabrication |  | Motherboard PCB | motherboard |  | 1 | 1 | 3.00 | 3.00 |  | N/A |  |  |  |  |  | Not an LCSC catalogue item (JLCPCB / your fab).
Assembly |  | PCB assembly |  |  |  |  | TBD |  | Not yet quoted (todo.txt: TBA) | N/A |  |  |  |  |  | Still TBD.
TOTAL |  |  |  |  |  |  |  | 720.58 | Sum of priced lines (populated qty). RS passive prices converted at 1 SEK = 0.1035 USD (Jul 2026), assumed ex-VAT. Was 717.70; +2.88 from the 100nF line going 160->224 units (C26-C33 folded in 2026-08-04). *** THIS TOTAL IS NOW UNDERSTATED: the new OPA2333 buffer stage adds 32 op-amps and 64 1k resistors that are TBD-priced and therefore contribute 0 here. At a plausible $1-2/op-amp that is $32-64 not yet counted. TBD items outstanding: assembly, U13-U16 OPA2333 (32 units, NEW), R28-R35 1k (64 units, NEW), 100k/20k 0603 dividers (72+64 units, needs requote after 0402->0603 footprint change), LEDs, R18 pull-up, U9 EEPROM. ALSO NOT YET IN THE DESIGN: 4x 100nF local decoupling for U13-U16 (one per package at pin 8) - nothing on +3.3V is within 12 mm of any op-amp as placed, so this is 32 more units for the 100nF line once added. RESOLVED 2026-07-30: 10uF caps (C96446), ferrite (C96708), R27 (C144117, value now 10 ohm not 1.5) |  |  |  |  |  | 308.93 | LCSC subtotal for the 17 PRICED lines. Was 307.38; +1.55 (100nF 160->224 units, C26-C33 folded in 2026-08-04 at the same 0.0242 break). NOT PRICED but now C-numbered: L1 ferrite C96708 x8, R27 C144117 x8 - both commodity, expect well under $1 combined. NOT PRICED and NOT C-numbered: U13-U16 OPA2333 x32 and R28-R35 1k x64 (both NEW 2026-08-04, see their rows - the 1k previously carried C154077, which is the 20k part and was wrong). EXCLUDED: XTR200 x64 (not stocked), Pico (assembly-only), Molex FFC x3 (obsolete), DSM2 DC-DC (not stocked), PCB fab and assembly. Prices are LCSC USD list, captured 2026-07-30, at the price break covering the system quantity; they exclude shipping, duty and VAT. Stock figures are a snapshot - LCSC does not hold them.

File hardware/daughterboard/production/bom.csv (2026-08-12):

Designator | Footprint | Quantity | Value | LCSC Part #
12V0, VREF1 | TestPoint_Pad_D1.0mm | 2 | TestPoint
C1, C10, C12, C14, C15, C17, C18, C19, C2, C20, C21, C22, C24, C26, C27, C28, C29, C3, C30, C31, C32, C33, C4, C5, C6, C7, C8, C9 | 0603 | 28 | 100nF | C14663
C11, C13, C16, C23 | 0603 | 4 | 1uF | C15849
C25 | 0603 | 1 | 10uF | C96446
D1 | 0603 | 1 | LED | C125114
L1 | 0603 | 1 | FerriteBead_0603_1.5A | C133937
R1, R10, R11, R12, R2, R3, R4, R9 | 0603 | 8 | 100k | C122538
R13, R14, R15, R16, R5, R6, R7, R8 | 0603 | 8 | 20k | C154077
R17 | 0603 | 1 | 500 | C23179
R18 | 0603 | 1 | 2.7k | C13167
R19, R20, R21, R22, R23, R24, R25, R26 | 0603 | 8 | 4.7k | C513565
R27 | 0603 | 1 | 10 | C144117
R28, R29, R30, R31, R32, R33, R34, R35 | 0603 | 8 | 1k | C22548
U0, U1, U2, U3, U4, U5, U6, U7 | WSON-10-1EP_2x3mm_P0.5mm_EP0.84x2.4mm | 8 | XTR200 | C52091642
U10 | SOIC-8_3.9x4.9mm_P1.27mm | 1 | REF5030EIDR
U11 | TSSOP-28-1EP_4.4x9.7mm_P0.65mm_EP3.05x7.56mm | 1 | AD7193
U13, U14, U15, U16 | Texas_S-PVSON-N8 | 4 | OPA2333xxDRB | C2058573
U20 | WQFN-16-1EP_3x3mm_P0.5mm_EP1.6x1.6mm | 1 | DAC80508ZR | C2679499
U8 | TSSOP-16_4.4x5mm_P0.65mm | 1 | SN74LV165 | C201716
U9 | SOT-23 | 1 | AT21CS01 | C616192

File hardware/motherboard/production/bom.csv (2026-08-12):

Designator | Footprint | Quantity | Value | LCSC Part #
A1 | RaspberryPi_Pico_SMD | 1 | RaspberryPi_Pico | C7203003
C1, C10, C2, C3, C4 | 0603 | 5 | 0.1uF | C14663
C5 | 1210 | 1 | 10uF | C77102
C6 | 0805 | 1 | 22uF | C45783
C7 | CP_Elec_8x10 | 1 | 220uF | C125981
C8, C9 | 0805 | 2 | 10uF | C84416
D1 | D_SMA | 1 | SS34 | C8678
D2 | D_SMB | 1 | SMBJ16A | C151254
D3, D4, D5 | 0603 | 3 | LED | C157740
D6 | D_SOD-123 | 1 | BZT52C18 | C192739
F1 | 1812 | 1 | 1812L150/24MR | C142805
J1, J2, J3, J4, J5, J6, J7, J8 | SAMTEC_PCIE-064-02-X-D-TH | 8 | PCIE-064-02-F-D-TH | C4597619
J10, J11, J9 | Hirose_FH12-50S-0.5SH_1x50-1MP_P0.50mm_Horizontal | 3 | Conn_01x50_MountingPin | C202116
J12 | BarrelJack_Horizontal | 1 | Barrel_Jack_Switch_Pin3Ring | C84007
J13 | PinHeader_1x02_P2.54mm_Vertical | 1 | Conn_01x02_Pin | C32713268
Q1 | SOT-23 | 1 | AO3407A | C15155
R1, R5, R6 | 0805 | 3 | 100k | C96346
R10 | 0805 | 1 | 22k | C114565
R2, R8 | 0805 | 2 | 4.7k | C431850
R3 | 0805 | 1 | 1.5k | C4310
R4 | 0805 | 1 | 680 | C17798
R7, R9 | 0805 | 2 | 10k | C84376
U1, U5 | TSSOP-16_4.4x5mm_P0.65mm | 2 | SN74HC138PWR | C157527
U2 | TSSOP-16_4.4x5mm_P0.65mm | 1 | TMUX1208PW | C494728
U3 | TSSOP-16_4.4x5mm_P0.65mm | 1 | SN74LV595 | C116847
U4 | WSON-6-1EP_2x2mm_P0.65mm_EP1x1.6mm_ThermalVias | 1 | LP5912-3.3DRV | C524780
U6 | Converter_DCDC_TRACO_TSR-1_THT | 1 | K7805-500R3 | C19188491

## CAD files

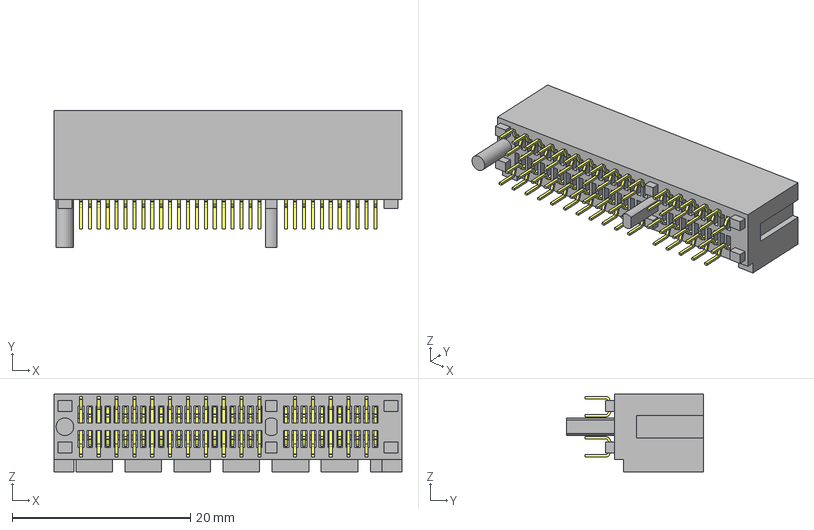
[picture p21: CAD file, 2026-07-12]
hardware/motherboard/PCIE-064-02-F-D-TH.stp
39.0 x 15.4 x 8.70 mm
PCIE-064-02-F-D-TH_body
PCIE-064-02-F-D-TH_pins1
PCIE-064-02-F-D-TH_pins2

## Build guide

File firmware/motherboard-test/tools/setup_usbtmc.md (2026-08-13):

# USBTMC instrument access (Keithley 2100)

The Keithley 2100 enumerates as `05e6:2100` and the kernel's `usbtmc` driver
gives it a `/dev/usbtmc*` node. That node is created `root:root 0600` by
default, so a plain user can't open it. One udev rule fixes it permanently.

## Install the rule (one time, needs sudo)

```sh
sudo tee /etc/udev/rules.d/99-usbtmc.rules >/dev/null <<'EOF'
# USBTMC test instruments — give plugdev users raw access to /dev/usbtmc*
SUBSYSTEM=="usbmisc", KERNEL=="usbtmc[0-9]*", MODE="0660", GROUP="plugdev"
SUBSYSTEM=="usb", ATTRS{idVendor}=="05e6", MODE="0660", GROUP="plugdev"
EOF
sudo udevadm control --reload-rules
sudo udevadm trigger --subsystem-match=usbmisc
```

`foosa` is already in `plugdev`, so no re-login is needed. Verify:

```sh
ls -l /dev/usbtmc*        # want  crw-rw---- root plugdev
```

If the node still shows `root root`, unplug and replug the 2100 — `udevadm
trigger` doesn't always re-run permissions on an already-attached device.

## Smoke test

Run in the jax venv (that's where the project's python deps live):

```sh
source /home/foosa/jax-env/jax_env/bin/activate
python tools/keithley2100.py
```

Expect an `*IDN?` line like `KEITHLEY INSTRUMENTS INC.,MODEL 2100,<serial>,<fw>`
followed by five DC-volt readings and their spread.

## Notes

- The node number is not stable across replugs (it was `/dev/usbtmc1` on
  2026-07-29, not `usbtmc0`). `autodetect_usbtmc()` matches on VID/PID via
  sysfs rather than assuming a number.
- `Keithley2100.set_timeout()` raises the USBTMC bulk-read timeout; the default
  used here is 10 s, which covers 100 NPLC (2 s/reading at 50 Hz) with margin.
- Always `config_vdc(high_z=True)` when probing a high-impedance node — the
  2100 defaults to a 10 MOhm input on the <=10 V ranges, which loads the node.
- The interface **stalls roughly once per few hundred readings**. A device CLEAR
  is not always enough; `reopen()` closes and reopens the node and replays the
  measurement config. This is wired into both `query()` and `read_burst()`.
- For speed, NPLC coercion, and the burst-read protocol traps, see
  `docs/characterization.md` §5B — the short version is **NPLC 1 with autozero
  off**, and **never trust a requested NPLC without measuring the achieved rate**.

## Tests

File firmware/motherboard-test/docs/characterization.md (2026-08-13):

# Channel characterization — accuracy, resolution, linearity

Bench record for the Koi 8×8 measurement and drive paths, taken against a
**Keithley 2100** 6.5-digit DMM automated over USB-TMC. Companion to
`measure-path-offset.md` (which covers the sense-path offset investigation
specifically).

**Rig, unless stated otherwise:** board 0, channel 0, load **1005.68 Ω**
(four-wire verified), 2100 connected across the load on a **fixed 10 V DCV
range** at 10 NPLC, 8 readings averaged per point. ADC at `RATE 96`, `AVG 4`,
gain 1, unipolar, SINC4, chopper off. Tools: `tools/keithley2100.py`,
`tools/vsweep_dmm.py`, `tools/resolution_test.py`.

### The reference load

Nominal 1 kΩ, **±1 % tolerance, 100 mW rating**; four-wire measured at
**1005.68 Ω** (+0.57 % of nominal, consistent with the tolerance).

- **Always use the measured 1005.68 Ω, never the 1 kΩ nominal.** The tolerance
  then drops out of every result. Assuming nominal would inject +0.57 % — larger
  than the drive gain error being measured. (Same trap as the single-point offset
  cal warned about in `measure-path-offset.md` §6.1.)
- **Power is never a concern here.** Full scale is 6.383 mA → **41.0 mW, 41 % of
  rating**. Reaching 100 mW needs 9.97 mA, above the firmware's 6.383 mA ceiling,
  so the part cannot be overrun through this instrument.
- **The tempco is NOT specified by the ±1 % tolerance** and is the parameter the
  self-heating arguments in §5A depend on. It is bounded from the data instead:
  - Explaining the whole measured INL as self-heating would require a tempco of
    only **1–4 ppm/°C** (Rth 850 → 200 °C/W). Thick film is 100–200 ppm/°C, metal
    film 50–100, carbon film −200 to −500 — so **self-heating is not the source of
    the INL.**
  - Fitting gain over restricted current ranges bounds where the heat does show
    up: −0.469 % (0.2–1.5 mA, 2.3 mW) → −0.481 % (0.2–6.4 mA, 41.2 mW). A real,
    monotonic trend with dissipation, but **only 0.012 % across an 18× power
    range**, i.e. ~2.5 % of the −0.48 % gain error.
  - Why it lands in gain and not INL: at 0.6 s dwell against a small resistor's
    ~10–100 s thermal time constant, a randomized sweep never lets the load reach
    its point-specific temperature — it sits near the run-average.
- **The four-wire value was measured cold**, and the load runs warmer during a
  sweep. Everything here uses the cold value (the right choice for consistency);
  that is the origin of the residual ~0.01–0.02 % on the gain figure.

> **Fix the DMM range for offset/accuracy work.** Autoranging splits a sweep
> across the 100 mV and 10 V range calibrations, and the difference between them
> lands directly in a fitted intercept of a few mV — exactly the quantity being
> measured.

## At a glance

| Quantity | Measured | Where |
| --- | --- | --- |
| Drive gain error | **−0.478 %** (`calSlope` 0.47 → **0.47226**) | §3 |
| Drive offset `I_OS` | +2.50 µA | §3 |
| Drive linearity (after gain+offset) | 0.0046 % FS | §3 |
| Sense residual, calibrated | **67 ppm FS** (max −423 µV) | §2 |
| Sense residual, nominal ×6 | 0.36 % FS | §2 |
| Resistance vs 4-wire truth | −0.4 % bias (drive), **±0.03–0.05 % scatter** | §5 |
| Measurement noise floor | **1.15 µV** at the ADC pin (RATE 96 / AVG 4) | §4 |
| Drive resolution | 1 LSB = **97.398 nA**, 65 536 codes | §5A |
| DNL / monotonicity | **±0.26 LSB / monotonic**, 0 non-monotonic in 96 | §5A |
| INL (randomized order) | **rms 1.01 LSB, max −2.24 LSB = 0.0034 % FS** | §5A |
| Effective resolution | **14.8 of 16 bits** | §5A |
| Usable sense range | **only above the node ≈44 mV knee** | `measure-path-offset.md` §5A |
| Usable `RATE` range | **≥16** (below that returns raw code 0) | §6.1 |
| Per-point settling | **0.8 s** converged; 0.3 s biases ~1.5 % | §5A |
| Fastest useful 2100 setting | **NPLC 1, autozero off** — 0.1 LSB in one reading | §5B |

**Everything here is one channel on one board (board 0, channel 0).** The
per-channel `I_OS` distribution, the sense knee, and the noise floor all still
need repeating across all 64 channels before any of it is published.

---

## 1. Compliance

No compliance limit over the full firmware range. Swept to 6.3 mA (6.26 V across
the load); incremental `dV/dI` stayed flat at 992.2–992.7 V/A and the XTR200
ERRORFLAG stayed clear at every point. The full 0–6.383 mA span is usable into a
~1 kΩ load.

## 2. Sense accuracy (Koi vs 2100)

69-point sweep, 0–6.3 mA. Fit over the 63 points above the low-signal knee
(§4 of `measure-path-offset.md`):

```
V_node = (V_ADC + 3.810 mV) × 5.9909
```

| quantity | value |
| --- | --- |
| residual after 2-parameter cal | max **−423 µV**, rms **110 µV** |
| — as fraction of 6.255 V full scale | **67 ppm** |
| residual using nominal ×6, no offset | max **+22.4 mV** = **0.36 % FS** |

So the sense path is worth ~70 ppm once calibrated, and ~0.4 % uncalibrated.

**Ratio caveat:** the in-situ fit returns 5.99, not the 6.0017 measured by
back-driving with the current source removed. This is *not* a divider error —
~1.86 Ω of series resistance in the load path between the divider tap and the
DMM connection carries the load current, so the divider sees `V_DMM + I·Rs`, a
current-proportional term that lands entirely in the fitted ratio. An in-situ
voltage-vs-voltage sweep can never measure the true ratio; use a back-drive
measurement for that, and in-situ sweeps for offset and linearity only.

## 3. Drive accuracy (2100 + the known resistor as current reference)

Actual sourced current derived as `I = V_DMM/1005.68 + V_DMM/120 kΩ` (load plus
the divider's share), fit against commanded current:

```
I_actual = 0.995218 × I_cmd + 2.496 µA
```

| quantity | value |
| --- | --- |
| **gain error** | **−0.478 %** → `calSlope` 0.47 seed should become **0.47226** |
| **XTR200 `I_OS`** | **+2.496 µA** (datasheet ±10 µA max; bench scatter ±4 µA) |
| **linearity residual** after gain+offset | max **0.30 µA** = **0.0046 % of 6.383 mA FS** |

The XTR200 itself is excellent — essentially all of the drive error is the
uncalibrated scale factor, confirming the "slope is a shared constant, offset is
per-channel" model. `calSlope`/`calOffset` remain at the ideal seed in firmware.

## 4. Measurement resolution (noise floor)

Channel 0 at 1.0 mA, 30 repeated reads per setting, 5 reads discarded after each
setting change (see the gotcha below).

| RATE | AVG | t/read | 1σ at ADC pin | 1σ at load | equivalent current | 2100's own 1σ |
| ---: | ---: | ---: | ---: | ---: | ---: | ---: |
| 16 | 4 | 55 ms | 3.42 µV | 20.5 µV | 20 nA | 8.25 µV |
| 96 | 1 | 81 ms | 2.16 µV | 12.9 µV | 12.9 nA | 7.35 µV |
| 96 | 4 | 320 ms | **1.15 µV** | 6.9 µV | 6.8 nA | 6.44 µV |
| 96 | 16 | 1277 ms | 1.74 µV | 10.5 µV | 10.4 nA | 7.97 µV |
| 240 | 4 | 796 ms | 1.28 µV | 7.7 µV | 7.7 nA | 4.72 µV |

Timing matches the `0.83 ms × FS × AVG` model exactly at every point.

**Past RATE 96 / AVG 4 you are at the floor.** RATE 96/AVG 16 measured *worse*
than 96/AVG 4, and with n = 30 the σ estimate itself carries ~13 % uncertainty,
so 1.1–1.7 µV is one flat floor rather than a trend. Spending 4× the time buys
nothing here. Note also that the Koi's pin-referred noise is *below* the 2100's
own spread over the same reads.

## 5. Resistance accuracy vs the 1.00568 kΩ reference

R computed from the Koi alone (calibrated sense model, commanded current,
divider correction applied):

| range | R from Koi | vs four-wire truth |
| --- | --- | --- |
| I ≥ 0.5 mA | 1001.94 ± 0.87 Ω | −0.372 % |
| I ≥ 1.0 mA | 1001.72 ± 0.49 Ω | −0.393 % |
| I ≥ 2.0 mA | 1001.53 ± 0.27 Ω | −0.412 % |

**The −0.4 % bias is the drive gain error of §3, not the sense path** — R is
computed from *commanded* current, which runs 0.478 % high. The meaningful
figure of merit is the **scatter, ±0.27–0.49 Ω (0.03–0.05 %)**, which is what
remains once `calSlope` is trimmed.

---

## 5A. Current-source resolution and linearity — 2100 only, ADC not used

`tools/dac_char.py`. The on-board ADC takes no part in this measurement; current
is derived entirely from the 2100's voltage across the four-wire load,
`I_source = V/R + V/120 kΩ`. The firmware maps current to code as
`code = round(mA · calSlope/VREF · 65535)`, so an exact code is commanded by
inverting that — which lets the DAC be stepped one LSB at a time.

### Scale

| quantity | value |
| --- | --- |
| DAC | 16-bit, **65 536 codes** over 0–6.3830 mA |
| **1 LSB** | **97.398 nA** = 97.95 µV across 1005.68 Ω |
| 2100 noise (10 NPLC, 10 reads) | 7.44 µV = **0.076 LSB** |

The reference resolves ~13 steps within one DAC LSB, so **every single code is
individually resolvable** and the DAC's LSB — not the measurement — sets the
resolution. Points measured: full range 128 points at 50.26 µA (516 LSB) spacing;
single-code sweeps of 33 codes (±16 LSB) centred on 1.0, 3.0 and 5.0 mA
(codes 10267, 30801, 51336).

### Accuracy (full range, 128 points)

```
I_actual = 0.995231 × I_cmd + 2.519 µA        gain −0.477 %,  I_OS +2.52 µA
```

This independently reproduces the ADC-inclusive sweep of §3
(0.995218, +2.496 µA) to 1.3 × 10⁻⁵ in gain and 23 nA in offset — two separate
sweeps, so the drive numbers are solid.

### Linearity

| quantity | value |
| --- | --- |
| **INL** | max −3.73 LSB, rms 1.46 LSB = 0.0057 % FS — **UPPER BOUND ONLY, thermally contaminated, see below** |
| effective resolution from INL | 14.1 of 16 bits — **do not quote, same contamination** |
| **DNL** | max **±0.26 LSB** across all three centres (±0.4 LSB worst over all later runs) |
| **monotonicity** | **0 non-monotonic steps in 96** — monotonic everywhere measured, every run |
| smallest observed step | +72.3 nA (0.74 LSB), at the 5 mA centre |

### INL — measure it in RANDOMIZED code order (`tools/inl_random.py`)

**Resolved.** A monotonic ramp gives a contaminated INL; randomized order with an
interleaved drift reference gives a defensible one, and the residual is *not*
thermal.

| method | INL max | rms | % FS |
| --- | --- | --- | --- |
| monotonic 0→6.38 mA ramp | −3.73 LSB | 1.46 | 0.0057 % |
| **randomized + drift-corrected** | **−2.24 LSB** | **1.01** | **0.0034 %** |

The ramp overstates INL by ~60 %. Method: 48 codes visited in random order, a
fixed reference point re-measured every 4 points, each datum corrected by the
reference interpolated to its timestamp. The interleaved reference drifted only
**13–25 ppm** across each ~60–110 s pass, versus the ~6-minute
monotonically-heating ramp it replaces.

Three independent random orders (2 passes each):

| seed | INL max | rms | gain |
| --- | --- | --- | --- |
| 1 | −2.40 LSB | 1.03 | −0.485 % |
| 7 | −2.07 LSB | 0.99 | −0.481 % |
| 13 | −2.24 LSB | 1.01 | −0.481 % |

**Quote the rms: 1.01 ± 0.02 LSB.** It is stable to 2 % across seeds, whereas the
max is an extremum statistic and scatters over 2.07–2.40 LSB. Gain reproduces to
−0.482 ± 0.002 %.

**The remaining INL is genuine converter nonlinearity, not load heating.**
Tested rather than assumed. Note the correct predictor is **I³, not I²**: heating
goes as `ΔT ∝ I²R`, but the reported *current* is `V/R_assumed`, so the current
error is `I·αΔT ∝ I³`.

| predictor | R² | INL after removing that term |
| --- | --- | --- |
| I (linear) | 0.000 | −2.24 LSB, rms 1.01 |
| I² | 0.055 | −1.96 LSB, rms 0.98 |
| **I³ (correct thermal term)** | **0.148** | −2.04 LSB, rms 0.93 |

Even the correct I³ predictor explains only ~15 % of the variance and removing it
changes the rms by 8 %. The measured shape is an **arch peaking near mid-scale**
(−2.00 LSB at 0.2 mA, +1.16 at 3.36 mA, −0.84 at 5.7 mA) — a concave-down
parabola, whereas a detrended cubic is S-shaped, which is why the fit is poor.

The decisive argument is the tempco bound above: explaining this INL thermally
needs 1–4 ppm/°C, which no ±1 % resistor achieves.

**Pass-to-pass repeatability is 0.13 LSB per code**, so −2.40 LSB is ~18× the
noise floor. Gain came out −0.485 %, reproducing the −0.478 % and −0.477 % of §3
and §5A from two other sweeps.

| quantity | value |
| --- | --- |
| **INL** | **rms 1.01 LSB, max −2.24 LSB = 0.0034 % FS** |
| **effective resolution** | **14.8 of 16 bits** (from max INL) |
| INL repeatability (floor on the claim) | 0.13–0.16 LSB per code |

### Always check the DMM error queue during acquisition

`inl_random.py` queries `SYST:ERR?` after every point and separately flags short
bursts and overload readings. This is not optional bookkeeping — it is what
distinguishes a corrupted run from a good one, and none of the earlier tools did
it (only `vsweep_dmm.py`, and only once after config).

In practice about **one `-113 "Undefined header"` per ~130 measurements** appears
at a random point. It is an artifact of the USBTMC stall recovery: recovering
re-issues commands while a `READ?` may still be pending, and the instrument logs
the garbled fragment. `reopen()` now sends `*CLS` so recovery artifacts are not
misattributed to the following measurement, which reduces but does not eliminate
them.

**These do not corrupt data**, and that is checked rather than assumed: they fire
only in the SCPI-queue category, never in the overload or short-burst checks; the
stored CSV has no out-of-range values and exactly the expected point count; and
the INL reproduces across three independent random orders. Treat an overload or
short-burst flag as fatal to a run; treat a lone `-113` as cosmetic.

> **Always randomize.** With a self-heating load, code order and thermal state
> are confounded in any monotonic sweep. Randomization plus an interleaved
> reference is cheap — the run above is ~2 minutes — and it is the difference
> between a 0.0057 % number and a 0.0037 % one.

### ⚠ Local step size measurements ARE contaminated by load self-heating

Separately from the INL above: an earlier version of this section reported local
step sizes of 98.27 / 96.75 / 94.84 nA at the 1 / 3 / 5 mA centres, argued they
were ~20σ significant, and attributed them to converter INL. **That attribution
was wrong.** The measurements are significant, but the cause is the load resistor
heating, not the DAC — these single-code sweeps were taken in monotonic order and
reached each centre by ramping up from the previous one.

Re-measured at the 5 mA centre after a **60 s soak at 5 mA**, varying only the
per-point settle time:

| settle | mean step | note |
| --- | --- | --- |
| 0.30 s | 96.65 nA | |
| 0.80 s | **97.88 nA** | converged |
| 1.50 s | **98.00 nA** | agrees with 0.80 s to 0.12 nA |
| 0.30 s (repeat) | 96.21 nA | repeatable low bias |

Two separate effects:

1. **0.3 s settle is insufficient**; it biases the mean step low by ~1.5 %.
   0.8 s is converged (0.8 s and 1.5 s agree well inside the ~0.22 nA
   statistical uncertainty).
2. **Thermal state dominates.** The soaked 5 mA step is **97.9 nA**, against
   94.84 nA originally. The original figure was taken by ramping up from the
   3 mA centre with the load still warming — that 3 nA (3 %) gap is the load
   drifting, not the converter.

**This is why the 128-point monotonic INL sweep read −3.73 LSB against the
randomized measurement's −2.40 LSB** (see above): it ramped 0 → 6.38 mA over
~6 minutes with dissipation rising 0 → 40 mW. For scale, a metal-film resistor at
~50 ppm/°C warming a few °C drifts ~250 ppm.

**What is unaffected:** DNL (±0.24 to ±0.4 LSB across every run) and
**monotonicity — 0 non-monotonic steps out of 96, reproduced in every run at
every centre and every settle time**. Both are differential measurements between
adjacent codes taken seconds apart, so slow thermal drift largely cancels.

**Per-centre local step sizes have not been re-measured in randomized order.**
The INL that superseded them was, so there is no outstanding number that depends
on these; treat the 98.27 / 96.75 / 94.84 figures as withdrawn rather than
corrected.

---

## 5B. How fast the 2100 can actually go

Driven by "run it as fast as the meter supports and see what breaks". Measured at
1 mA, 200-reading bursts, 1 LSB = 97.95 µV at the load:

| NPLC req. | autozero | readings/s | 1σ | 1σ / LSB | time to reach 0.1 LSB |
| ---: | --- | ---: | ---: | ---: | ---: |
| 0.02 | off | 304.5 | 66.01 µV | 0.674 | 0.149 s |
| 0.02 | on | 434.1 | 69.88 µV | 0.713 | 0.117 s |
| **1** | **off** | **39.9** | **9.80 µV** | **0.100** | **0.025 s** |
| 1 | on | 34.9 | 11.37 µV | 0.116 | 0.039 s |
| 10 | off | 4.4 | 10.68 µV | 0.109 | 0.271 s |
| 10 | on | 3.2 | 9.24 µV | 0.094 | 0.274 s |

**NPLC 1 with autozero off is the optimum.** A *single* reading already gives
0.100 LSB. NPLC 10 is 10× slower for identical noise — it buys nothing here.
NPLC 0.02 is genuinely fast (up to 434 readings/s) but noisy enough (0.7 LSB)
that reaching 0.1 LSB needs ~45 averaged readings, making it 6× slower overall
than just using NPLC 1.

At 0.025 s/point this is **~80× faster** than the 2.0 s/point (10 reads × NPLC 10)
used for the §5A campaign, at the same precision. **The DMM was never the
bottleneck — settling is** (§5A).

### Use burst reads, not one `READ?` per value

At low NPLC the USB round-trip, not integration, limits `read()` throughput.
`Keithley2100.read_burst(n)` sets `SAMP:COUN n` and fetches all n in one
transfer. Two traps found implementing it:

- **A burst reply spans several USBTMC messages.** A single `os.read()` returned
  16 of 100 requested values, truncated mid-number. Replies carry no trailing
  newline (USBTMC marks end-of-message out of band) and a short read does not
  imply the last message, so the only reliable termination is **counting
  values** — `read_values()` does this.
- **An unread remainder poisons the next session.** The leftover ~1.4 kB sat in
  the instrument's output buffer and was parsed as commands on the next
  connection, surfacing as spurious `-108 "Parameter not allowed"` errors that
  looked like a config bug. Always drain the full reply.

### The 2100 silently coerces NPLC

Requested vs. what `SENS:VOLT:DC:NPLC?` reports back, **with no SCPI error**:

| requested | 0.02 | 0.06 | 0.2 | 1 | 10 | 100 |
| --- | --- | --- | --- | --- | --- | --- |
| reported | 1 | 10 | 10 | 1 | 10 | 10 |

`NPLC 0.2` really integrates at 10, which is why a 200-reading burst at
"NPLC 0.2" took 60 s — identical to NPLC 10. Timing behaviour did *not* always
match the readback either (the 0.02 request ran at 300+ readings/s, far faster
than NPLC 1 permits), so **trust measured throughput over either the request or
the readback**, and always report the achieved rate.

---

## 6. Firmware and bench gotchas found during this campaign

### 6.1 `RATE` below 16 is broken — do not use, and do not quote the FS=8 tables

At `RATE` 4, 8 and 12 **both** readout paths return raw code 0 — `MEAS?` gives
exactly `0.0000000` and `MEASA?` gives `nan` — on a signal known good at
0.16224 V. `RATE` 16, 24, 32 and 96 all read correctly. `AVG` is irrelevant and
both paths fail together, so it is the ADC configuration at low filter words,
not the read path.

| RATE | `MEAS?` | `MEASA?` |
| --- | --- | --- |
| 4, 8, 12 | `0.0000000` | `nan` |
| 16, 24, 32, 96 | 0.16224 ✓ | 0.16224 ✓ |

**Consequence:** CLAUDE.md's "Measured timing vs RATE" table lists FS=8 (600 Hz
ODR, 0.45 s full grid) as bench-measured, and its entire `AVG n` noise table was
taken at FS=8. **Neither is reproducible as written.** Re-measure before quoting
either, in the paper or anywhere else.

The firmware still replies `OK RATE <n>` for these values, so a bad setting is
silently accepted and only surfaces as zero readings. **Treat RATE 16 as the
practical minimum.**

### 6.2 A `RATE` change needs settling

The first conversions after a filter-rate change are invalid — observed as
all-zero codes and, in one run, a 0.13 V spread while settling. Discard ~5 reads
after changing `RATE` before measuring or timing.

### 6.3 Raw code 0 looks different in each polarity

A wedged ADC returns raw code `0x000000`, which reads as **`0.0` in unipolar**
and **`−3.0 V` (−VREF) in bipolar**. Check for both; a sweep over a wedged ADC
still fits a perfectly plausible straight line.

### 6.4 Two ways to wedge the ADC

- **`CAL` while `BIPOLAR ON`** wedges it immediately. Do not recalibrate in
  bipolar — bipolar sweeps are accurate *without* a recal, and adding one
  destroys them. (The tempting analogy with `GAIN`'s required zero-scale recal
  does not hold.)
- **Toggling `XTR` mid-session** desyncs it: readings survive but come back with
  a bogus ~−676 mV offset and a ~6.5 incremental ratio. Set the front-end state
  once at session start and leave it.

Both recover on reopening the serial port, which resets the Pico.

### 6.5 `MEASA?` can exceed the host's command deadline

At `RATE 96 × AVG 16` a single-board `MEASA?` takes ~10.2 s and blows
`KoiLink.command()`'s 10 s deadline, returning `None`. Use `MEAS? g` for
high-AVG single-channel work.

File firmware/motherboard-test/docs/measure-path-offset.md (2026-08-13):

# Measure-path offset investigation (the "10 mV error")

Engineering record for the residual measurement error on the Koi 8×8 sense path.
Last bench session: **2026-07-25**.

**Status: root cause NOT yet confirmed.** Every component outside the AD7193 has been
eliminated by direct measurement. One hypothesis remains standing and its decisive test
has not been run.

---

## 1. The symptom

The ADC under-reads by roughly **3.4 mV at the ADC pin** (≈ 20 mV heater-referred through
the 6:1 divider) whenever there is signal on the input. At zero input it does *not* under-read —
it reads **+0.29 mV**.

Originally this presented as a ~10 mV error and was mistaken for a 2 % gain error, because a
fixed offset is 2.2 % of a 0.163 V signal but 0.43 % of a 0.826 V signal. Percentage error that
shrinks as signal grows is the signature of an offset, not a gain term. **This confusion has
cost the project two separate debugging cycles — see §6.**

## 2. Bench rig (2026-07-25)

The XTR200 for the channel under test was **physically desoldered**, and the divider's 100k was
later lifted. This removes the entire drive path and lets a source meter force the sense node
directly, which is what made the measurement conclusive.

- **Keithley 2410 SMU** — forces the node voltage. HI on the divider input pad, LO on the board
  ground (bypass-cap ground, via two Dupont connectors).
- **Keithley 2100 DMM** — verifies the forced voltage.
- Load: **999.8 Ω**, 4-wire measured.

## 3. Data

### 3.1 SMU forcing the divider input (XTR200 removed, divider intact)

| applied (2100-verified) | SMU current | ADC raw |
| --- | --- | --- |
| 1.00050 V | — | 163.331 mV |
| 3.0014 V | 3.0162 mA | 496.720 mV |

Two-point fit:

```
D = (3.0014 − 1.00050) / (0.496720 − 0.163331) = 6.0017
k = 1.00050/6.0017 − 0.163331                  = 3.372 mV

raw = V_node / 6.0017 − 3.372 mV
```

This measurement **decided the offset-vs-gain question**. Predictions going in were 496.68 mV
(fixed offset) vs 490.00 mV (−2.2 % gain); the measurement landed at 496.720 — a 40 µV hit on a
6.7 mV fork.

Two consequences:

- **The divider is nominal to 0.03 %.** The host's fixed **×6.0 is correct** — do not "correct"
  it, and do not let the GUI's "Sweep + cal" adjust the divider ratio. The earlier ÷5.990 figure
  was an artifact of measuring through the XTR200.
- The entire residual is **one additive ~3.4 mV term**.

It is additive, not proportional to load current: `raw₂/raw₁ = 3.0412` against
`V₂/V₁ = 2.99990`. A load-current-proportional term (1.0 → 3.0 mA) would make those equal.
This rules out ground-return IR drop.

### 3.2 Zero input

| condition | reading |
| --- | --- |
| XTR200 disabled | 0.290 mV |
| XTR200 physically removed | 0.290 mV |
| 100k lifted (nothing on pin but 20k to GND) | ~0.3 mV |
| 100k lifted, **CHOP ON** | 0.001 mV |

The zero-point offset is therefore **entirely internal to the AD7193** — nothing external
contributes — and it is **choppable**. It matches the known gain-1 zero-scale calibration
artifact: `writeBoardConfig` runs the internal cal with `AD7193_CONF_CHAN(0)` selected, so the
shared offset register is trimmed for channel 0 and channels 1–7 carry that correction plus
their own mux-path offset (measured per board: b0 ~0.28, b2 ~0.72, b6 ~1.4 mV).

**The split between these two terms is the key diagnostic result:**

| term | choppable? | depends on input level? |
| --- | --- | --- |
| +0.29 mV at zero | **yes** (→ 0.001 mV) | no |
| −3.4 mV at signal | **no** | apparently yes |

CHOP cancels a fixed internal offset. It does not touch the 3.4 mV. Whatever causes the 3.4 mV
is therefore *not* a fixed internal offset but a level-dependent input-stage error.

### 3.3 Supporting measurements

| quantity | measured | spec/nominal | error |
| --- | --- | --- | --- |
| VREF | 2.9998 V | 3.0000 (hardcoded `ADC_VREF`) | 0.007 % |
| DAC @ 0.470 V cmd | 0.47014 / 0.47040 / 0.47030 | 0.470 | +0.03…0.085 % |
| load resistor (4-wire) | 999.8 Ω | 1 kΩ | −0.02 % |
| divider pin→GND | 16.691 kΩ | 20k‖(100k+1k) = 16.694 | ✓ |
| divider pin→node | 17.354 kΩ | 100k‖(20k+1k) = 17.355 | ✓ |
| AINCOM → local ground | 0 mV | 0 | ✓ |
| SMU LO → local ground | 0 mV | 0 | ✓ |

DAC scatter is 0.26 mV ≈ 5.7 LSB (1 LSB = 45.8 µV), i.e. offset scatter rather than
quantization. Referred through the 0.47 V/mA transconductance that is 0.85 µA worst case —
well inside the ±4 µA IOS scatter and not significant.

## 4. Eliminated by measurement

| suspect | verdict | evidence |
| --- | --- | --- |
| drive path / XTR200 | out | chip physically desoldered, error persists |
| DAC accuracy | out | 0.03 % at 0.470 V |
| voltage reference | out | 2.9998 V (0.007 %) |
| divider ratio | out | 6.0017 from SMU fit; ohmmeter agrees |
| load resistor tolerance | out | 999.8 Ω 4-wire |
| solder joints / divider integrity | out | 16.691 / 17.354 kΩ textbook |
| PCB ground / PDN | out | padne FEM, <0.3 µV |
| AINCOM ground reference | out | 0 mV to local ground |
| SMU LO reference offset | out | LO on board ground, 0 mV |
| ground-return IR drop | out | additive, not current-proportional (§3.1) |
| AD7193 internal offset | out | CHOP no-op at signal; measured floor tens of µV |
| aliased noise / oscillation | out | reading is rock-stable |
| input filter cap (absent) | real but not causal | stable reading rules out AC rectification |

## 5. Buffered common-mode range — **REFUTED 2026-07-29**

> **This hypothesis is dead.** Its sharp prediction — a knee at pin = 250 mV (node 1.5 V,
> ~1.5 mA) — was tested directly by a 16-point in-situ sweep and does not exist: the
> per-point offset runs flat through 250 mV (−3.708 mV at pin 5 mV → −3.780 at pin 250 mV
> → −3.750 at pin 494 mV). **There *is* a knee, but it is at pin 7.3 mV, not 250 mV**, and
> it is a gain change rather than an offset. See §5A. The section below is kept for the
> record of what was ruled out and why.

**UNCONFIRMED. This is the only mechanism not yet eliminated.**

With `BUF` enabled, the AD719x family restricts the *absolute* input voltage range to
approximately **AGND + 250 mV to AVDD − 250 mV**, and that applies to **AINCOM as well as AIN**.

On this board **AINCOM is tied to AGND (0 V)** — permanently ~250 mV below the valid range,
and it has been since bring-up, on all 8 boards. An input stage operating without headroom
produces millivolts of offset, is not covered by the offset spec, and is not cancelled by
chopping because it is not a fixed internal offset.

What it explains:

- additive and roughly constant across pin = 167 mV and 500 mV
- unaffected by CHOP
- AINCOM measuring 0 mV to local ground (*that is the problem, not the disproof*)
- ~0 at zero input — the internal zero-scale cal runs at zero and absorbs the error at that
  point; as AIN rises the error changes and a residual is left
- offset apparently larger at low current — below node 1.5 V the pin is under 250 mV so *both*
  inputs are out of range; above it only AINCOM is

**Sharp prediction: a knee at pin = 250 mV**, i.e. node = 1.5 V, i.e. ~1.5 mA into 1 kΩ.
Error falling steeply below it and flattening above ⇒ confirmed.

### Decisive test (not yet run)

With the 100k lifted, drive the ADC pin directly from the SMU (its output impedance dominates
the 20k, which draws only 25 µA at 500 mV):

| forced at pin | ADC clean | ADC is the problem |
| --- | --- | --- |
| 167.000 mV | 167.3 mV | ~163.6 mV |
| 500.000 mV | 500.3 mV | ~496.6 mV |

Then repeat with **`AD7193_CONF_BUF` off**. Unbuffered range is AGND − 50 mV to AVDD + 50 mV,
so 0 V AINCOM becomes legal. Offset collapsing to tens of µV confirms the hypothesis.

Because the SMU drives the pin directly, unbuffered mode has no source-impedance penalty —
this is the only clean way to A/B the buffer. Driving unbuffered from the 16.7 kΩ divider
would introduce a switched-cap gain error and confound the result.

**If steps above are ambiguous**, the definitive discriminator changes the common mode and
nothing else: lift AINCOM off ground, hold it at ~500 mV from a bench supply, put AIN at
~1000 mV. Same 500 mV differential, both pins now inside the buffered range. Offset vanishing
⇒ common-mode range, full stop.

### If confirmed, the fix is a board change

Not trivial, and worth knowing before committing:

- **Cannot simply bias AINCOM up** to 250 mV — the signal is 0–500 mV ground-referenced and
  unipolar mode needs AIN ≥ AINCOM. That would require level-shifting the whole measurement.
- **Run unbuffered behind a low-offset op-amp buffer** (chopper-stabilized, e.g. OPA333 at
  ~10 µV offset) — keeps the 0 V reference and gives unbuffered mode the low source impedance
  it needs.
- **Re-scale the divider** low enough to drive unbuffered mode directly — simplest electrically,
  but steals proportionally more current from the heater node.

Also note: an out-of-range input stage will drift with temperature and vary part to part, so
a calibrated constant measured today is not guaranteed to hold tomorrow. That is the argument
against simply subtracting 3.372 mV and moving on.

## 5A. 2026-07-29 — it is a LOW-VOLTAGE GAIN DEFICIT, not an offset

**Rig:** channel 0, XTR200 *installed*, 1005.68 Ω load (4-wire), Keithley 2100 across the load
**automated** over USBTMC (`tools/keithley2100.py`), swept by `tools/vsweep_dmm.py`. Fixed 10 V
DCV range, 10 NPLC, 8 readings/point; ADC at RATE 96 / AVG 4 / gain 1 / SINC4 / chop off.
Automation is what made this findable — it costs nothing to take 16 points × 8 readings, and
the structure only shows up if you sample below 0.05 mA, which no hand-taken dataset ever did.

### The measurement

| cmd mA | node mV | pin mV | incremental ratio | implied offset mV |
| ---: | ---: | ---: | ---: | ---: |
| 0.000 | 2.808 | 0.185 | — | −0.284 |
| 0.005 | 7.180 | 0.484 | 14.59 | −0.714 |
| 0.010 | 12.222 | 0.886 | 12.55 | −1.154 |
| 0.015 | 17.161 | 1.296 | 12.05 | −1.569 |
| 0.020 | 22.096 | 1.711 | 11.89 | −1.977 |
| 0.025 | 27.090 | 2.134 | 11.81 | −2.388 |
| 0.030 | 32.012 | 2.556 | 11.65 | −2.787 |
| 0.040 | 41.994 | 3.456 | 11.10 | −3.553 |
| 0.050 | 51.828 | 4.945 | **6.60** | −3.705 |
| 0.075 | 76.696 | 9.076 | 6.02 | −3.725 |
| 0.100 | 101.553 | 13.209 | 6.01 | −3.741 |
| 0.200 | 200.752 | 29.731 | 6.00 | −3.776 |
| 1.000 | 994.923 | 162.242 | 5.993 | −3.817 |
| 2.000 | 1987.582 | 327.953 | 5.990 | −3.786 |
| 3.000 | 2980.190 | 493.659 | 5.990 | −3.753 |

Two clean linear regimes:

| regime | span | fit | r² |
| --- | --- | --- | --- |
| **low** | 0.005–0.04 mA (node ≤ 42 mV) | `pin = node/11.729 − 0.157 mV` | 0.99954 |
| **high** | 0.05–3.0 mA | `pin = node/5.992 − 3.748 mV` | **1.0000000** |

They cross at **node 44.0 mV / pin 7.3 mV** (~43.7 µA).

### What it means

**The famous −3.4 mV additive offset is not additive and is not an offset.** The low regime's
intercept is **−0.157 mV, i.e. essentially zero** — at small signals the path has no offset,
only about *half* the correct gain (11.73 vs 5.99). The sense path therefore reaches the knee
already ~3.6 mV short, and above the knee it tracks with the *correct* slope forever. To anyone
sampling only above 0.05 mA — which is every prior dataset in this document — that is
indistinguishable from a perfect fixed offset.

*Honesty about the arithmetic:* "high intercept = low line extrapolated through the crossover"
closes to 0.0004 mV, but that is tautological — the crossover was derived from the two fits.
The non-circular content is **low intercept ≈ 0 vs high intercept = −3.75 mV**. That is what
says the offset is *generated by* the gain transition rather than existing on its own.

### Implied mechanism

A current drawn from the ADC pin that is **ohmic (~17.4 kΩ) below ~3.9 mV and saturates at
~225 nA** above it (225 nA × (100k‖20k = 16.67 kΩ) = 3.75 mV). Resistive-then-constant-current
is the signature of a leaky junction / ESD structure. **225 nA is ~200× the AD7193's buffered
input-leakage spec**, so if it is the ADC's own input it is out of spec; it could equally be a
board leakage path onto the ~16.7 kΩ node. Note this also explains why the power-off ohmmeter
checks looked textbook (16.691 kΩ pin→GND): an ohmmeter cannot see a 225 nA saturating leak.

### Decisive next test

DMM the **ADC pin itself** while sweeping the same low-current points. If the *pin voltage*
shows the 11.73 → 5.99 knee, the current is being drawn at the node → board/ESD leakage, fixable
upstream. If the pin tracks a clean 6:1 and only the reported code shows the knee, it is inside
the AD7193. (Caveat from §7: hanging a meter on this unfiltered node perturbs it — take the
comparison with the meter attached for *all* points so the perturbation is common-mode.)

### Also settled this session

- **Not a unipolar clamp** (the obvious suspect): 0 mA reads 0.000182 V unipolar vs 0.000183 V
  bipolar — identical, and bipolar can represent negatives. Cross-check at 1 mA: 0.1622400 vs
  0.1622383.
- **The ÷5.990 "through-XTR200 artifact" is ~1.86 Ω of series resistance** in the load path
  between the divider tap and the DMM clip point: `6.0017/(1 + Rs/1005.68) = 5.9906` → Rs = 1.86 Ω.
  The divider sees `V_dmm + I·Rs`, proportional to current, so it lands entirely in the fitted
  ratio. **The host's fixed ×6.0 remains correct.** Consequence: an in-situ V-vs-V sweep can
  never measure the true divider ratio — it will always read ~5.991. Use the desoldered/back-drive
  rig for ratio, in-situ only for offset/linearity.

## 6. Methodology warnings

### 6.1 Do not derive the offset by forcing R to read exactly 1 kΩ

The tempting in-situ method — command a known current, compute R, adjust an offset until
R = 1000 Ω — assumes three things that are false:

1. **The resistor is 1000 Ω.** It is 999.8 Ω (4-wire).
2. **The commanded current is the actual current.** XTR200 IOS is ±4 µA measured — **±0.4 % at
   1 mA** — and is per-channel.
3. **A single point can separate offset from gain.** It cannot; at one current they are
   algebraically indistinguishable.

The resulting number is not a measure-side offset. It is a catch-all absorbing drive error +
load tolerance + measure error, and it will differ at every current and on every channel.
**This plausibly explains the reported "offset varies pin to pin and with current"** — IOS is
per-channel (pin-to-pin), and single-point fitting against a non-offset error gives a different
answer at every current by construction. Those observations may be artifacts of the method.

**Instead, measure the three paths independently:**

- **Measure path** — force known voltages on the pin with the SMU (50, 100, 167, 250, 350,
  500 mV), read the ADC, fit. No resistor, no current, no XTR, no assumptions. Reveals whether
  the error is offset, gain, or curved, and directly tests the 250 mV knee.
- **Divider** — already known independently (6.0017, plus the ohmmeter readings).
- **Drive path** — characterize separately by *measuring* current rather than assuming it.

If an in-situ calibration on assembled channels is unavoidable, **sweep and fit** (intercept =
offset, slope = gain) rather than single-point — this needs no assumed R, and is already the
recommended method for the current-side offset table.

### 6.2 Absolute mV vs percent

Before concluding "the offset changes with current", check whether it is changing in absolute
mV or as a percentage of signal. A constant 3.4 mV reads as 8.1 % at 0.25 mA, 2.0 % at 1 mA and
0.68 % at 3 mA. This is the error that made the term look like a 2 % gain error and it has
recurred twice.

## 7. Bench gotchas from this campaign

- **Back-driving the divider pad draws the load current.** 1 V into 1 kΩ‖120 kΩ ≈ 1.01 mA;
  3 V ≈ 3.03 mA. Set SMU compliance accordingly (5 mA for the 3 V point). A compliance trip
  turns the SMU into a current source and the node never reaches the set voltage, making any
  reading meaningless.
- **With the XTR200 installed, forcing >~1–2 V on its output pin makes an ESD clamp conduct.**
  Measured >5 mA at 3 V against 3.03 mA expected. Provably nonlinear: a linear parallel path
  could not go from ≤0.49 mA at 1 V to >1.97 mA at 3 V. This is a **bench artifact only** — in
  normal operation the XTR200 sources current and nothing back-drives that pin. Remove the chip
  to take back-drive points.
- **Rework hazard.** An improperly resoldered XTR200 read **67.228 mV at zero command** —
  ~407 µA of output current, ~40× the ±10 µA datasheet IOS max, equivalent to ~190 mV of input
  offset. A bad joint on ground, an input, or the set resistor makes the part obey a bogus
  input. This is not leakage. After any rework, re-verify the divider against the known-good
  baselines (pin→GND 16.691 kΩ, pin→node 17.354 kΩ) before trusting any offset number.
- **A DMM lead left floating in air reads a few mV of ambient pickup.** It is not a
  measurement. One such reading nearly sent this investigation down a false path because it
  happened to land near the value being hunted.
- **Probing the unfiltered ~16.7 kΩ sense node perturbs it** (a DMM on the pin once shifted it
  ~30 mV and the ADC followed). There is no input filter cap on this design. Adding ~0.1 µF C0G
  at each input is worthwhile for probe immunity and EMI — BUF is on and the divider's 16.7 kΩ
  is series R, so no DC gain error, τ ≈ 1.7 ms — but it is **not** the cause of the 3.4 mV.

## 8. Open questions

1. **Does the ADC alone show the 3.4 mV?** (§5 decisive test — not yet run.)
2. **Does BUF off remove it?**
3. **Is there a knee at pin = 250 mV?** Requires the low-end sweep, which also settles §6.2.
4. **Is the pin-to-pin variation real, or the §6.1 method artifact?** Cannot be answered from
   measurements that involve XTR200s and loads. Nail one channel with SMU + ADC only first.
5. **Forced 0.000 V with the SMU connected** was never taken. It closes the loop on whether the
   zero point is genuinely different or just a different circuit configuration.

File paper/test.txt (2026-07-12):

================================================================================
KOI 8x8 — VALIDATION & CHARACTERIZATION TEST PLAN
Feeds Section 7 (Validation) of the HardwareX manuscript.
Status: [ ] = not started   [~] = partial   [x] = done
================================================================================

--------------------------------------------------------------------------------
INSTRUMENTS NEEDED (to borrow / get lab access to)
--------------------------------------------------------------------------------
MUST HAVE
  * Calibrated SMU — Keithley 2400 / 2450 (have 2400; CHECK ITS CAL DATE,
    ask the owning lab for the cal certificate)
  * 6.5-digit DMM — Keysight 34461A / 34465A, or Keithley DMM6500 / 2000.
    This is the independent cross-check for everything; highest priority loan.
  * Precision reference resistors — Vishay foil (Z-foil / VPG) or similar,
    0.01–0.1 % tolerance, <=25 ppm/K TCR, values spanning the load range
    (~200 ohm – 2 kohm). These go on the precision-resistor PCB.
  * GPIB/USB adapter for the 2400 (already planned) or use RS-232.
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

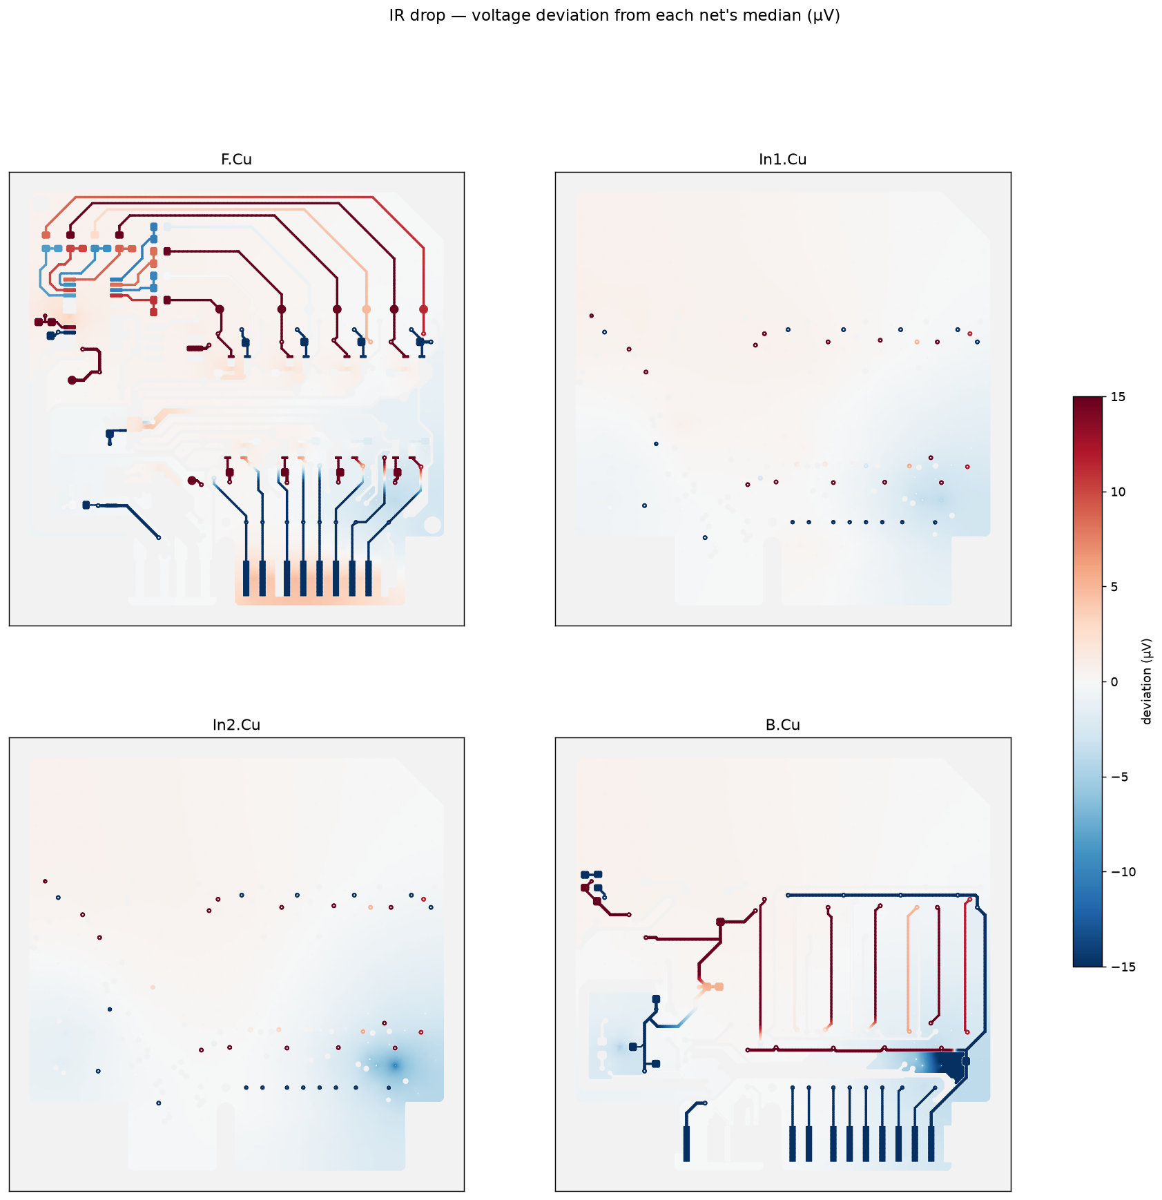
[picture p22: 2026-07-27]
hardware/daughterboard/results_v3/ir_drop.png

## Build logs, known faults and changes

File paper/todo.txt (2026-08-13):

Koi 8x8 — paper TODO / working notes
=====================================
(Scratch file. A clean repo with finalized design files + BOM will be created
separately for the paper submission. This just parks data so it isn't lost.)

BILL OF MATERIALS — provisional pricing (per-unit)
--------------------------------------------------
Counts note: 66 XTR200 / 66 resistors imply spares (64 channels = 8 boards x 8).
REF5030 count is 8 — one per daughterboard, each board's DAC+ADC share it;
there is NO 9th ref on the controller (earlier "8 + 1 main = 9" was wrong).
Confirm
whether the paper BOM should quote the *populated* count (64) or the
*ordered* count (incl. spares) — HardwareX wants build-cost, so ordered qty
with a note is fine.

--- Daughterboard analog (x8 boards) ---
  66  XTR200          @ $1.456   =  $96.10
   8  DAC80508        @ $15.50   = $124.00   [was written $144.00 — 8x15.5=124.00]
   8  AD7193          @ $18.13   = $145.04   [was written $144.00 — 8x18.13=145.04]
  66  Resistors       @ $1.00    =  $66.00
   8  REF5030         @ $6.00    =  $48.00   [was 9 — wrong, no ref on controller]
  25  Capacitors      @ $0.50    =  $12.50

--- Controller / MOBO ---
   1  RP2040          @ $7.00    =   $7.00
   2  SN74LV138       @ $0.49    =   $0.98
   1  SN74LV595       @ $1.00    =   $1.00
   1  DSM2-12-S3-S    @ $10.37   =  $10.37
   3  FFC             @ $3.00    =   $9.00   [AMBIGUOUS: $3 each (=$9) or $3 total? confirm]
   1  Jack            @ $1.00    =   $1.00

--- PCB ---
   8  Analog PCB      @ $30.00   = $240.00
   1  Main PCB        @ $3.00    =   $3.00

--- Assembly ---
   TBA

SYSTEM TOTAL (corrected multiplications, 8 refs, FFC as $3 ea): ~$763.99
  Per-channel (64 ch): ~$11.94/channel
  (If FFC is $3 total, subtract $6 -> ~$757.99, ~$11.84/ch)

Compare against Qontrol / multichannel Keithley 2400-class SMU per-channel
cost for the "fraction of the cost" claim in the abstract/spec table.

BOM PRESENTATION — decision
---------------------------
Q: itemize each passive, or lump them for the paper?
A: Do BOTH, split by venue (this is standard HardwareX practice, and the
   draft's BOM-section comment already anticipates it):
   - PAPER main-text "Bill of materials summary" table: LUMP. One line each
     for "Resistors" and "Capacitors" (qty + total). Reviewers want the major
     cost drivers legible, not 25 identical 0.1uF rows. Group by function.
   - SUPPLEMENTARY CSV (released with design files): ITEMIZE every part with
     designator, value, qty, unit cost, supplier, MPN. This is the
     reproducibility artifact and HardwareX expects a complete itemized BOM.
   So: grouped in the paper, fully itemized in the supp. CSV.

OFFSET-CURRENT ANOMALY (BLOCKER for all IOS / calibration numbers)
------------------------------------------------------------------
- Uniform -24 uA static offset on ALL channels of boards 0-2 (2026-07-03
  sweep). 2.4x datasheet max IOS and uniform across parts => systematic,
  not per-part offset. MUST be solved on the devkit before Sec. 7 numbers.
- Progress: ~10 uA attributed to leakage current. Remaining ~14 uA
  unattributed — find where it goes (current-side vs measurement-side;
  run the test.txt Section 2 isolation ladder: shorted-input ADC offset,
  front-end disabled leakage, enabled zero-command, DMM at the ADC pin).
- Closed-loop TiN demo and final cal campaign are gated on this.

CAL FIXTURING — TEST-SETUP ACTION PLAN (updated 2026-07-06)
------------------------------------------------------------
Primary method: DMM-across-known-load (V/R), NOT Keithley-in-series on all
64 ch. One DMM reading per point gives heater V directly and I = V/R_meas
(+ V/120k divider term). Metrologically stronger than the 2400's ammeter
(~30 ppm DMM + ~100 ppm R  vs  ~0.03 % + offset for the 2400) and never
breaks the current path, so all 64 channels stay loaded and driven while
scanning (representative operating conditions; no compliance railing).

Loads (cost decision — do NOT buy 64 foil resistors):
- 64x cheap 0.1 %, 25 ppm/K thin-film 1 kOhm (1206/2512 or 2 W package to
  tame self-heating), EACH measured 4-wire with the 6.5-digit DMM. Value
  comes from measurement, not the part grade.
- 1-2x VPG foil resistors TOTAL, as bench transfer standards only (check
  DMM ranges, spot-check channels).
- Self-heating budget at 6 mA into 1 k (36 mW): ~3-4 K in a 1206 ->
  ~90 ppm @ 25 ppm/K -> ~0.5 uA at FS, scales as I^2. Bound it, or
  re-measure R warm; log ambient with every dataset.

Jig PCB:
- 2-pole (both ends of load) switching tree routes the DMM across one
  channel's load at a time. Relays preferred (pA open-contact leakage —
  no leakage argument during the -24 uA hunt); if solid-state, must be
  high-voltage mux class (TMUX6108 / MUX36S08 / ADG1408). TMUX1108 is OUT:
  5.5 V max, heater node hits ~12 V and rails ~18-20 V when unloaded.
- If Keithley-in-series is ever inserted: per-channel SPDT (form C) so
  deselected channels keep their ground return; switch on the LOW side;
  never hot-switch (command 0 mA first). Plain 8:1 mux in the current
  path is WRONG (open-circuits the other 7 loads -> compliance rail).
- Drive: shift register + relay driver (TPIC6B595 / ULN2803) from the
  jig's own RP2040 (reuse the 595 pattern).
- Release the jig (schematic, PCB, BOM, control script) as open design
  files — "open calibration fixture" is a HardwareX-valued contribution.

Jig PCB — 4-wire / Kelvin layout rules (added 2026-07-10):
- KELVIN GEOMETRY, NOT MORE SWITCHING: the 2-pole tree is already
  effectively 4-wire during the sweep (DMM hi-Z -> no current in the
  sense path, so relay/trace R drops nothing). The requirement is that
  the two sense traces branch DIRECTLY AT THE LOAD PADS — any shared
  segment upstream carries the 6 mA drive current and its IR drop lands
  inside the measurement. Route each sense pair together to the tree.
- Run the DMM in hi-Z (10 GOhm) input mode; the fixed 10 MOhm mode
  steals ~1 uA at 12 V from the sense node (bigger than any switch
  error). Check which ranges keep hi-Z on the actual DMM (>10 V ranges
  often force 10 MOhm) — matters for the 2 kOhm subset at 6 mA (12 V).
- R_meas — DECIDED 2026-07-10: IN-SITU 4-WIRE OHMS via one 4PDT per
  load (supersedes the earlier bench-premeasure plan). Sense pair at
  the pads -> Keithley 2100 SENSE terminals; force pair at the pads ->
  2100 INPUT terminals. DCV sweeps use the INPUT pair (still Kelvin at
  the pads); 4W ohms uses both. Benefits: no bench premeasure /
  bookkeeping of 64 loose parts, R measured through the same taps as
  the sweep, and "re-measure R warm" / drift checks = just re-run the
  ohms scan. Rules: NEVER 4W-ohm a driven channel (2100 sources test
  current into the node); do ohms scans with the harness disconnected
  (else reading = R // 120k divider, -0.83% at 1k — correctable but
  avoid). 2-wire ohms through the tree stays forbidden (relay+cable R
  = 200-1000 ppm on 1k).
- Ohms-scan procedure (2026-07-10): any external current through the
  load adds I_ext x R to the DMM reading (3 mA drive = 300% error;
  even enabled-at-0 IOS = 0.4-2.4%). So: (1) command 0 + XTR 0x00
  (disabled leakage 0.35 nA = 0.35 ppm of the 1 mA test current);
  (2) use the 2100's OFFSET-COMPENSATED OHMS — V measured with test
  current on and off, so any CONSTANT residual current / thermal EMF
  cancels exactly; (3) warm re-measure = soak at setpoint, disable,
  trigger ohms within ~1 s (2512 thermal tau ~10+ s), script the
  timing. Harness-on reading = R // 120k: exact correction but divider
  tolerance leaves ~83 ppm — prefer harness-off, budget the term when
  warm-scanning harness-on.
- Relay sourcing: G6A-474P (4PDT) is discontinued. Build 4 poles/ch by
  GANGING 2x commodity DPDT per channel (one driver bit drives both
  coils; Hongfa HFD2 / Axicom IM / TQ2 class, ~$70-90 for 46) — or
  Fujitsu FTR-B4 if a true 4PDT is stocked.
- Parameter separation (2026-07-10) — how the "two unknowns" (divider,
  IOS) decouple; structure the analysis script this way:
  1. CURRENT-SIDE FIT (DMM only): I_true = V_dmm/R_meas + V_dmm/120k;
     fit vs commanded -> calSlope (shared) + calOffset (IOS). The 6:1
     ratio NEVER enters (DMM measures the load directly); the divider
     appears only via the stolen-current term. Divider parts are 0.1%
     -> residual ~17 ppm of I even at the 2k/2V worst case (16.7 uA
     stolen, corrected to ~+-17 nA). Negligible, no cal needed.
     NB stolen current scales with V -> on a fixed-R sweep it is a
     GAIN error (-0.83% at 1k if uncorrected), never a static offset:
     independent proof the -24 uA anomaly is NOT a divider-correction
     bug. ADC buffered input (~GOhm) sits on the divider TAP: ~20 ppm
     ratio shift + nA bias current, both absorbed by the voltage-side
     fit.
  2. VOLTAGE-SIDE FIT (same sweep): regress onboard ADC raw V against
     V_dmm -> per-channel effective ratio (replaces the default 6.0;
     lumps divider ratio + ADC gain + ref — fine, ratiometric) +
     intercept = ADC-path offset (the GUI "Offset+ mV").
  3. TWO-LOAD RE-RUN attributes any anomalous offset (-24 uA) to
     side 1 vs side 2.
  Bonus: harness-off vs harness-on ohms scans give each channel's
  actual 120k shunt (sensitivity diluted ~120x, but same-meter
  differential precision ~10-20 ppm -> 120k to a few 0.1%), if the
  70 ppm ever needs tightening.
- Considered & REJECTED (2026-07-10): raising the divider to 100M/20M
  to shrink the stolen current. The V/120k term is KNOWN (analytic,
  ~70 ppm residual); 100M/20M replaces it with UNCORRECTABLE errors:
  AD7193 buffered-input bias (nA-class, temp-doubling) x 16.7M source
  impedance = 17-50 mV at the pin; PCB surface leakage (GOhm-class,
  HASL/flux) vs a 100M leg = %-level ratio shifts; >=10M parts are
  thick film only (1-5%, bad TCR, voltage coefficient -> nonlinear
  ratio); RC settling + Johnson noise hurt the continuous scan.
  Design rule for the paper: prefer a large KNOWN term over a small
  UNKNOWN one. (If ever needed: 1M/200k thin film or a buffered tap —
  no respin justified at current accuracy targets.)
- Keithley 2100 notes: USB-TMC (pyvisa, no GPIB). Hi-Z (>10 GOhm)
  input only on <=10 V ranges; 100 V range is fixed 10 MOhm -> cap the
  2 kOhm subset at ~4.8 mA (stay on 10 V range) or correct the ~1.2 uA
  the 10 MOhm steals at 12 V.
- Jig topology DECIDED 2026-07-10: 23-channel relay bank (one 50-pin
  FFC = 23 ch), 2 cable swaps cover 64 ch. CONSTRAINT: the 64 loads
  are PERMANENTLY on the jig and all three drive FFCs stay plugged in
  for the whole campaign — the moved cable is a jig-local SENSE-ONLY
  jumper between three headers and the relay bank. Never unplug a
  drive FFC mid-campaign: ~41 unloaded channels rail to 18-20 V next
  to the measurement (kills the all-64-loaded-and-driven condition and
  contaminates the board-leakage hunt). Part numbering trap: Omron
  G6A-274P = DPDT, G6A-474P = 4PDT — in-situ 4W ohms needs the 474P
  (+ second 50-pin sense jumper, 23 ch x 4 = 92 pins); 274P = sense
  only -> bench-premeasure the loads. DC3 coils need MOSFET-output
  drivers (TPIC6B595 from 3.3 V); ULN2803's ~0.9 V drop starves a 3 V
  coil. Crosstalk figure on board 0 or 1 (board 2 straddles the 23-ch
  group boundary at g22/g23).
- Loads: tolerance grade is free (value comes from the ohms scan) but
  buy THIN FILM (thick film has voltage coefficient, tens of ppm/V ->
  fake nonlinearity across the 0.3-6 V sweep) with TCR <=25-50 ppm/K
  and a big package (self-heating ~1-2 K at 36 mW).
- Drive path short and fat (connector -> load -> ground return). Its R
  is outside the taps so it doesn't corrupt the DMM number, but it adds
  drop between the load and the daughterboard's divider node -> shows up
  in the onboard-ADC-vs-DMM readback comparison. Keep harness drop small.
- Silkscreen designators + a measurement log keying each R_meas to its
  channel index (the cal math uses measured value, not nominal).
- No star-ground heroics needed: with true 2-pole sensing at the pads,
  the ground return only carries current, not metrology.
- Relay-count note (explored 2026-07-10): an 8+8 two-stage relay tree
  does NOT work with 2-pole relays — the board-select stage needs 16
  poles (8 ch x 2 wires), and the naive shared-channel-bus wiring would
  hard-short same-index channels of different boards (live sources)
  together. Buildable version = 40 packages, costs MORE than 64 cheap
  DPDTs. If minimizing count: solid-state 8:1 HV mux tree (TMUX6108 /
  MUX36S08, +-36 V; high Ron irrelevant in the hi-Z sense path, check
  MAX off-leakage over temp) + 2-3 relay-switched golden channels as a
  junction-free cross-check. See mouser.txt options (a)-(c).

Campaign structure:
- Main dataset (Qontrol-comparable): ALL 64 ch at measured 1 kOhm,
  0.25-6 mA sweep both directions.
- Two-load subset: ONE board re-run at ~300 Ohm and ~2 kOhm. Single-R
  sweeps have V = I*R perfectly correlated -> can't separate I-scaling
  errors (XTR gain, true IOS, DAC) from V-scaling errors (leakage,
  divider correction, ADC/divider gain). Same I at 2x V: if apparent
  offset moves -> leakage/measurement-side; if not -> genuine XTR IOS.
  This one figure attributes the -24 uA anomaly, validates the V/120k
  correction, exercises more ADC span, and shows load-independence
  (which Qontrol doesn't even publish — differentiator).
- Keithley 2400 in series on a FEW channels (manual cabling): independent
  cross-check of the V/R method (test.txt step 0.2 closes traceability).

Paper: describe the setup in the MAIN TEXT (Calibration method subsection):
instrument list + cal status, jig topology diagram, and a small uncertainty
budget table (DMM V, R tolerance/TCR/self-heating, divider term -> total I
uncertainty vs the +-4 uA IOS being resolved). Full jig detail goes in the
supplementary / repo, not omitted.

CLOSED-LOOP CLAIM
-----------------
- Closed-loop tuning is a headline claim of the paper — it needs real TiN
  heater test data (R vs power, servo demo). Scheduled LAST: after the
  offset anomaly is solved and the measurement chain is tightened.

THERMAL / "NO HEATSINKING" CLAIM (added 2026-07-06)
----------------------------------------------------
- The paper now claims (Sec 2.1) that 8 XTR200s per board need no
  heatsinking. Back it with data (new Sec 7 "Thermal validation"):
  worst case ~(Vsupply - Vload) x I ~= 120 mW/part at 6 mA into a
  near-short -> ~1 W per fully driven board across 8 packages.
- Test: all 64 ch at max current into low-R loads, thermal soak to
  steady state; IR camera / thermocouple on packages + board; report
  temp rise AND the induced current/reference drift (ties into the
  warm-up + overnight drift tests). Note derating for stacked/enclosed
  operation if needed.
- Framing: distributed dissipation is standard practice (Qontrol does
  the same) — validate the claim, don't sell it as novelty.

ASSEMBLY
--------
- Paper must state assembly method + cost (hand reflow w/ stencil vs PCBA
  service; DAC80508/AD7193 are fine-pitch). Include in BOM system total.
  \todo added in main.tex BOM section.

NAMING — RESOLVED 2026-07-06
----------------------------
- Renamed MOBO -> Koi everywhere: firmware *IDN? now "KOI,8x8,fw1.1",
  boot banner "# KOI 8x8", GUI renamed mobo_gui.py -> koi_gui.py
  (class MoboLink -> KoiLink), tool imports + CLAUDE.md + paper updated.
  GUI accepts both KOI and MOBO IDN prefixes until the Pico is reflashed.
  REFLASH the Pico (pio run -t upload) to complete the rename.

EXISTING-SOLUTIONS SURVEY (added 2026-07-06, extend before submission)
----------------------------------------------------------------------
- Added to refs.bib + Section 1: Qontrol Q8a/Q8iv (commercial), Sacchi et
  al. 2025 Light Sci Appl 8-ch CMOS ASIC controller (research, not open),
  uSMU (open single-channel SMU), plus background refs (Bogaerts 2020,
  Clements 2016, Harris 2014, Milanizadeh 2019 — VERIFY-marked entries).
- Still to do: systematic sweep of HardwareX / JOSS / OSF / GitHub for open
  multichannel drivers; record Qontrol list prices for the cost comparison.

OPEN PAPER TODOs (from \todo{} markers in main.tex)
---------------------------------------------------
- Author list, affiliations, corresponding author.
authors are Rohan Yadgirkar(rohany@kth.se), Ali Elshaari(elshaari@kth.se)

- Fill final per-channel cost into abstract + spec table + BOM total.
- Confirm closest-commercial-analog products + prices (Qontrol Q8iv/BP,
  Keithley 2400-class).
- Confirm open-source licenses (HW: CERN-OHL-S v2; FW/SW: MIT).
- Zenodo DOI + GitHub URL for source repo.
- Figures: system block diagram; calibration plots; noise vs RATE/AVG.
- Transcribe subsystem prose from CLAUDE.md (HC138, AD7193 continuous scan,
  DAC80508 ref/gain, XTR595 active-low enable).
- Validation section: Keithley 2400 sweep 0.25-6 mA, per-channel cal,
  span error / nonlinearity, IOS scatter, sense-divider correction check,
  full 64-ch scan time, crosstalk + board-to-board reproducibility.
- Bib: replace TODO cite keys, add refs.bib entries.

CHARACTERIZATION PLAN — mirror Qontrol Q8a current-mode suite
------------------------------------------------------------
Replicate the Q8a datasheet's per-parameter METHODOLOGY on Koi and report
Koi's OWN measured data next to Q8a's published specs (attributed). Do NOT
copy their numbers. Range differs (Koi 0-6 mA / ~0-18 V heater vs Q8a
0-100 mA / 0-12 V), so also report resolution & precision as % of full scale,
not just raw uA, or the comparison is apples-to-oranges.

Bench: Keithley 2400 as external current reference (GPIB/SCPI), sweep each
channel 0.25-6 mA (linear regime; sub-100 uA unreliable - source can't sink).

Current-mode measurements to take (figure placeholders already in main.tex,
see \label references):
  [fig:i-transfer]        Current transfer function: nominal vs measured, all
                          64 ch; + fine (single-code) panel.
  [fig:i-deviation]       Current deviation from nominal, TWO curves:
                            (a) vs external DMM/Keithley -> source accuracy
                            (b) vs onboard AD7193 readback -> closed-loop
                                measurement accuracy (after divider correction)
  [fig:i-linearity]       Single-code current step-size histogram (DAC LSB over
                          0-6 mA); current-mode DNL; current-mode INL.
  [fig:i-precision]       Current std dev at a fixed setpoint (e.g. 3 mA),
                          report as 1-sigma.
  [fig:i-crosstalk-power] Current-mode crosstalk (drive ch1-7 aggressors, watch
                          ch0 victim); power-into-load vs current w/ Pmax point.

Comparison-table columns to fill (Koi measured | Q8a spec | units):
  - current output range          | 0-6 mA        | 0-100 mA
  - current resolution (LSB)       | ? (~16-bit/6mA => finer) | 1.6 uA
  - current output precision (1s)  | ?             | 500 nA
  - current measure precision      | ?             | 1.9 uA
  - current-mode crosstalk         | ?             | 5 uA
  Report Koi's uA figures AND as %FS so the smaller range is honest.

Also (own device, not from Q8a): sense-divider correction validation, ADC
noise vs RATE/AVG, full 64-ch scan throughput, board-to-board reproducibility.

NAMING / FIRMWARE FOLLOW-UP — DONE 2026-07-06 (see "NAMING — RESOLVED" above)
-----------------------------------------------------------------------------
- Firmware, GUI, tools, CLAUDE.md and paper all renamed to Koi.
- Remaining: reflash the Pico; optionally rename the repo dir (mobo-test).

XTR200 FAULT DETECTION (EF CHAIN) — ADDED 2026-08-08, TO REDO ON fw1.3
-----------------------------------------------------------------------------
STATUS 2026-08-13: the code described below was REVERTED. Syncing the bench
tree (fw1.1 -> fw1.3, commit 62bf0ca) dropped include/EFChain.h, src/EFChain.cpp
and the FAULT? / FAULTCLR / FAULTEN commands, because it was never bench-tested
and the bench firmware had moved on. fw1.3 reads the same chain as ERR?, which
returns one raw 64-bit snapshot and leaves the open-drain polarity, the sticky
latch and the auto-zero policy to the host.
To rebuild on fw1.3: git show 62bf0ca^:firmware/motherboard-test/src/EFChain.cpp
(likewise include/EFChain.h). The verification list below still stands, and the
permutation tables in particular were never confirmed against hardware.

Original note follows.

Firmware landed: include/EFChain.h, src/EFChain.cpp, main.cpp poll/latch +
FAULT? / FAULTCLR / FAULTEN commands. Builds clean; NOT yet bench-tested.

The hardware was already there and unread: each daughterboard's SN74LV165 (U8)
samples its 8 XTR200 EF pins, and the motherboard daisy-chains all eight into
one 64-bit register (board0 -> ... -> board7 -> Pico) on a private 3-wire bus,
CP=GP16 / Q7=GP17 / PL=GP18 — independent of both SPI banks.

BENCH VERIFICATION NEEDED (in order):
  [ ] Boot prints "# EF chain valid boards: 0xFF" and no boot fault.
  [ ] The two permutation tables in EFChain.cpp (EF_SHIFT_TO_CH at :14 and
      EF_SHIFT_TO_BOARD at :19). Daughterboard scrambles EF->'165 inputs
      (A=U1 B=U3 C=U5 D=U0 E=U4 F=U7 G=U2 H=U6), same spirit as the DAC
      permutation. Test: FAULTEN OFF, open one channel, ISET g 3, FAULT? —
      confirm the lit bit is channel g. Repeat on a 2nd board for board order.
  [ ] GP16/17/18 themselves. Taken from motherboard production/netlist.ipc;
      9 other nets there match main.cpp exactly, BUT that file shows GP7
      unconnected while XTR_RCLK works there, so it lags the built board.
  [ ] Does EF stay asserted while OD is high? FAULTEN OFF, toggle a board's
      XTR enable, watch `now=`. Determines whether pollFaults()'s
      "skip disabled boards" guard is necessary — and settles whether a
      hardware auto-shutdown would latch or oscillate (see below).

KNOWN LIMITS (documented in firmware CLAUDE.md):
  - EF is ONE shared flag: open / saturation / SET short / supply UV (<8 V) /
    die >150 C. Disambiguate against MEAS? (railed voltage => open load).
  - Open detection arms only above VIN 350 mV = IOUT ~0.75 mA with
    RSET = 4.7k. Below that, an open heater raises nothing — needs the
    resistance check (R = 6*Vadc/I) to cover the sub-0.75 mA region.
  - A missing board breaks the chain (removes its '165, floats next DS).
    Boards downstream of the highest gap still read; upstream is garbage.
    efValidMask() computes it, FAULT? reports it as valid=.

DECIDED AGAINST (revisit only with evidence):
  - Per-channel OD via an extra '595. DAC=0 already gives a per-channel kill;
    residual is IOS (+/-14 uA over temp = 7 mV / 0.1 uW into 500 R) vs OD's
    10 nA. Not worth 8 more parts + SPI traffic + board area.
  - Hardware auto-shutdown (gates OR'ing EF into OD). Without a latch it
    oscillates; OD is board-wide so a trip kills 8 channels; EF asserts on
    every power-up UV ramp so it needs power-good gating (3-4 packages). And
    with the 6.4 mA RSET ceiling there is no failure mode faster than a
    thermal time constant, so 20 ms polling is already far ahead of it.

HARDWARE FOLLOW-UPS FROM THE SAME REVIEW — 2026-08-08
-----------------------------------------------------------------------------
[ ] R19-R26 (RSET, 4.7k) TEMPCO — highest-value change for the planned
    resistance-thermometry scheme. RSET tolerance/TCR converts directly into
    output-current error: ordinary 100 ppm/K thick film over a 20 K enclosure
    swing = 2e-3 current error ~ 4 K of APPARENT die temperature, which swamps
    what the measurement is trying to resolve. Specify 10 ppm/K or better.
    (Note the DAC and AD7193 share the REF5030, so reference drift already
    cancels in R = V/I — RSET is what's left.)

[ ] XTR_OD DEFAULT STATE IS AMBIGUOUS. R17 (500 R) + D1 (LED) sit from XTR_OD
    to GND as a "disabled" indicator. When the motherboard isn't driving B11
    (power-up before RCLK, unprogrammed '595, board seated w/o host), the net
    is 8x 4 uA internal pull-ups (32 uA) against the LED clamping down. At
    32 uA the LED sits ~1.4-1.6 V; the OD high threshold is 1.3 V min /
    1.65 V max — right on it. FIX: ~100k pull-up from XTR_OD to +3.3V on the
    daughterboard. Doesn't disturb the LED, '595 sinks the 33 uA trivially.
    Worth doing given firmware CLAUDE.md already documents marginal SPI frames
    corrupting DAC config.

[ ] VSP = 12 V is generous now that full scale is 6.4 mA. At a 3 V load the
    XTR200 drops 9 V => ~58 mW/channel, ~460 mW per daughterboard, dissipated
    directly under the analog front end. This is a thermal-DRIFT problem for
    the thermometry scheme, not a safety one (an open channel just sits at
    ~9.5 V passing 80 uA into the 120k divider; datasheet floor is VSP >= 8 V,
    output disables below 7.4 V). Also note max workable load at 6.4 mA is
    (12 - 2.5)/6.4mA ~ 1.5 kohm before the channel saturates.

[ ] EF lines have NO external pull-ups — they rely on the XTR200's 4 uA
    internal source into the '165 inputs. Fine DC into CMOS, but high-Z. If
    FAULT? reads come back flaky, add 100k pull-ups rather than chasing it in
    firmware.

PAPER / LIT-REVIEW ITEM — 2026-08-08
-----------------------------------------------------------------------------
[ ] Establish novelty of the resistance-self-sensing idea before writing it up
    as a contribution. Ingredients are all published: metal heater as its own
    thermistor; per-node current-vs-optical-power sweeps; thermal crosstalk as
    a linear power->phase matrix to invert (Milanizadeh et al., JLT ~2019,
    Politecnico di Milano — verify citation); in-situ feedback normally done
    OPTICALLY (tapped Ge PDs, or the same group's CLIPP transparent detectors;
    iPronics ships PD-based monitoring). What looks underexploited is the
    specific move: using the residual between measured and calibrated R at
    every channel simultaneously as a distributed on-die thermometer array,
    replacing an O(N^2) pairwise crosstalk campaign with N sensors already
    paid for. Needs a proper search — it's the kind of thing buried in a
    methods section.
    NOTE on the characterisation plan: isolation sweeps at a SINGLE ambient
    cannot separate self-heating from ambient (one equation, two unknowns).
    Run them at 3-4 deliberately different global ambients (TEC setpoints, or
    a fixed background power on unrelated channels) — that calibrates the
    thermometer and yields per-channel TCR as a fitted parameter. Also sweep
    up AND down (hysteresis vs within-sweep drift), dwell long at a few points
    (heater settles in us-ms, die/carrier over seconds-minutes — and that slow
    tail IS the drift being cancelled), and span enough fringes to resolve
    phase mod 2pi.

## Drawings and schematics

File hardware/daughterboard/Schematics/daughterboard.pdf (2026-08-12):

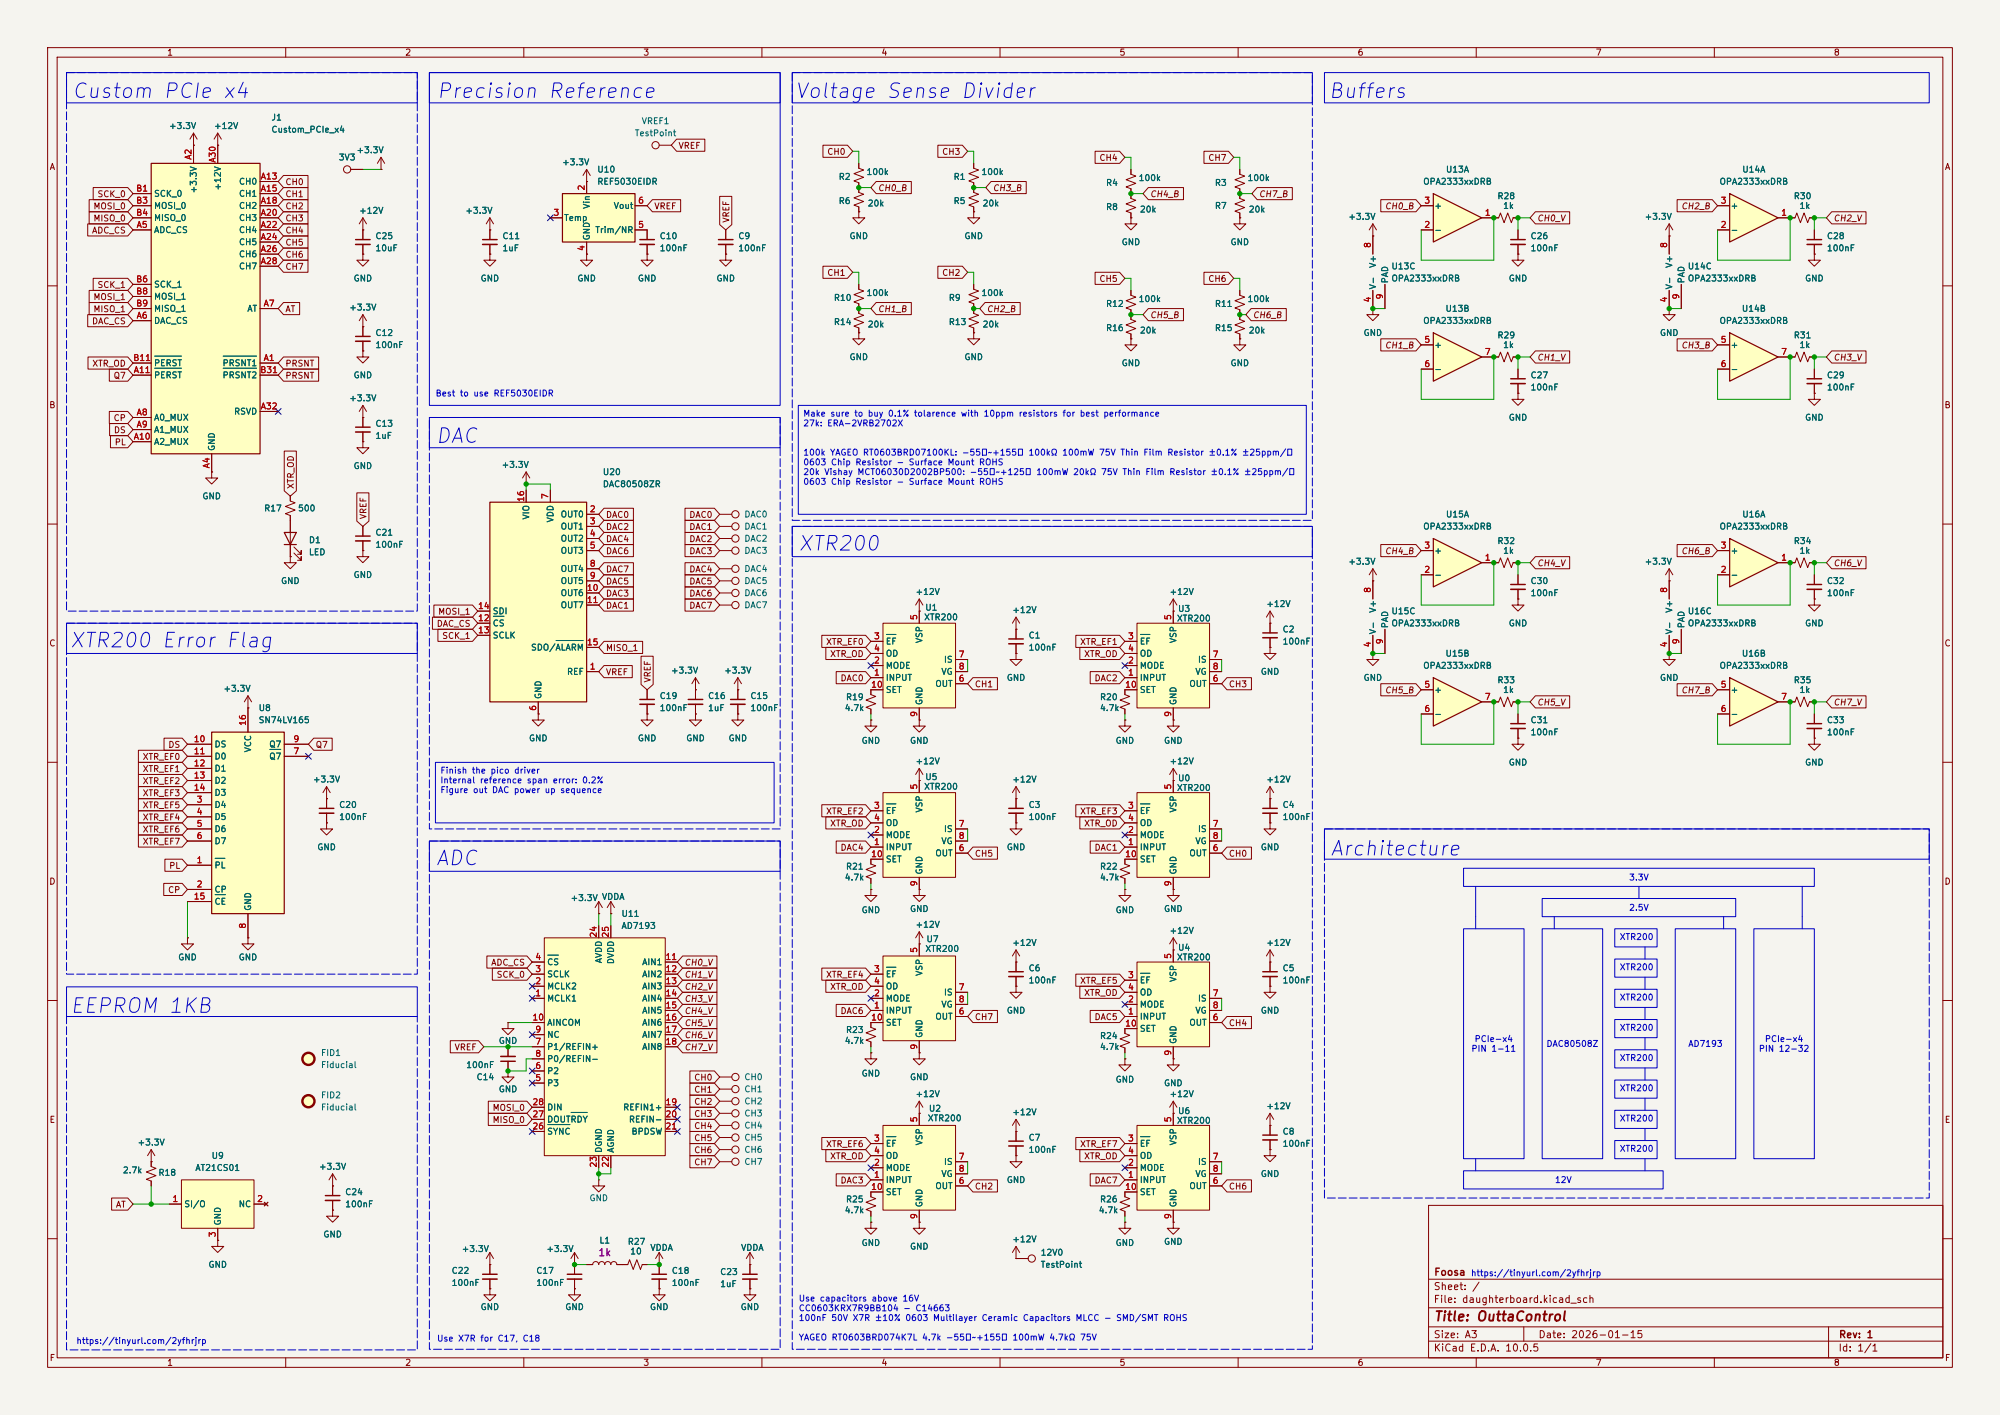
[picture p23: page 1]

Make sure to buy 0.1% tolarence with 10ppm resistors for best performance 27k: ERA-2VRB2702X

100k YAGEO RT0603BRD07100KL: -55℃~+155℃ 100kΩ 100mW 75V Thin Film Resistor ±0.1% ±25ppm/℃
0603 Chip Resistor - Surface Mount ROHS
20k Vishay MCT06030D2002BP500: -55℃~+125℃ 100mW 20kΩ 75V Thin Film Resistor ±0.1% ±25ppm/℃

Finish the pico driver
Internal reference span error: 0.2%

100nF 50V X7R ±10% 0603 Multilayer Ceramic Capacitors MLCC - SMD/SMT ROHS

Size: A3 | Rev: 1 | F Date: 2026-01-15
KiCad E.D.A. 10.0.5 | Id: 1/1

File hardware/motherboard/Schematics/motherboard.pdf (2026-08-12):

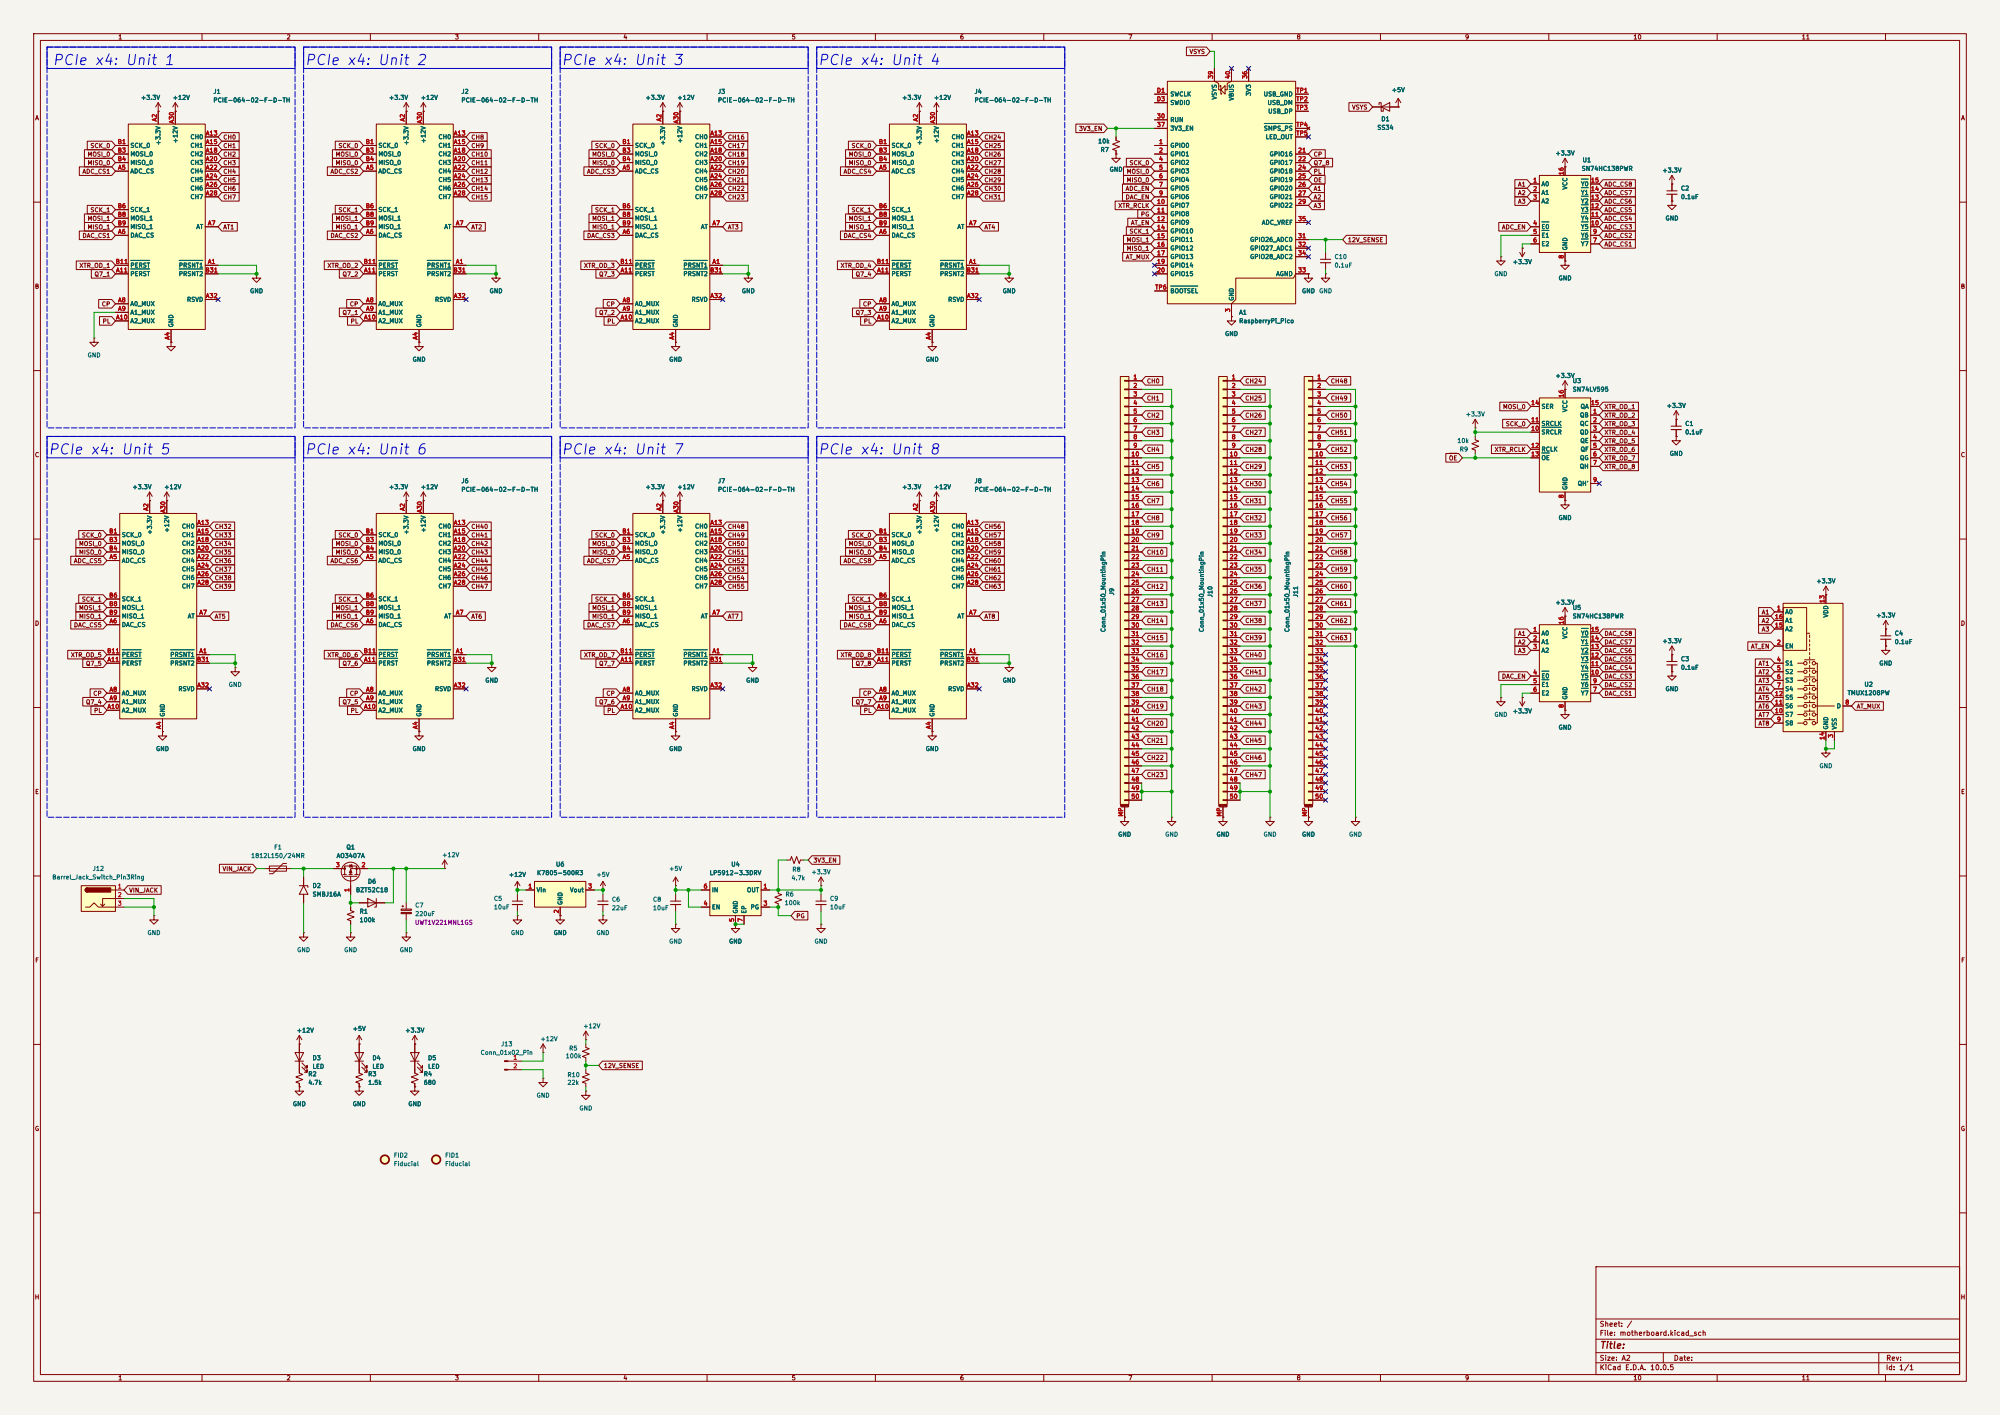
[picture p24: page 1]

Size: A2 | Rev:
KiCad E.D.A. 10.0.5 | Id: 1/1

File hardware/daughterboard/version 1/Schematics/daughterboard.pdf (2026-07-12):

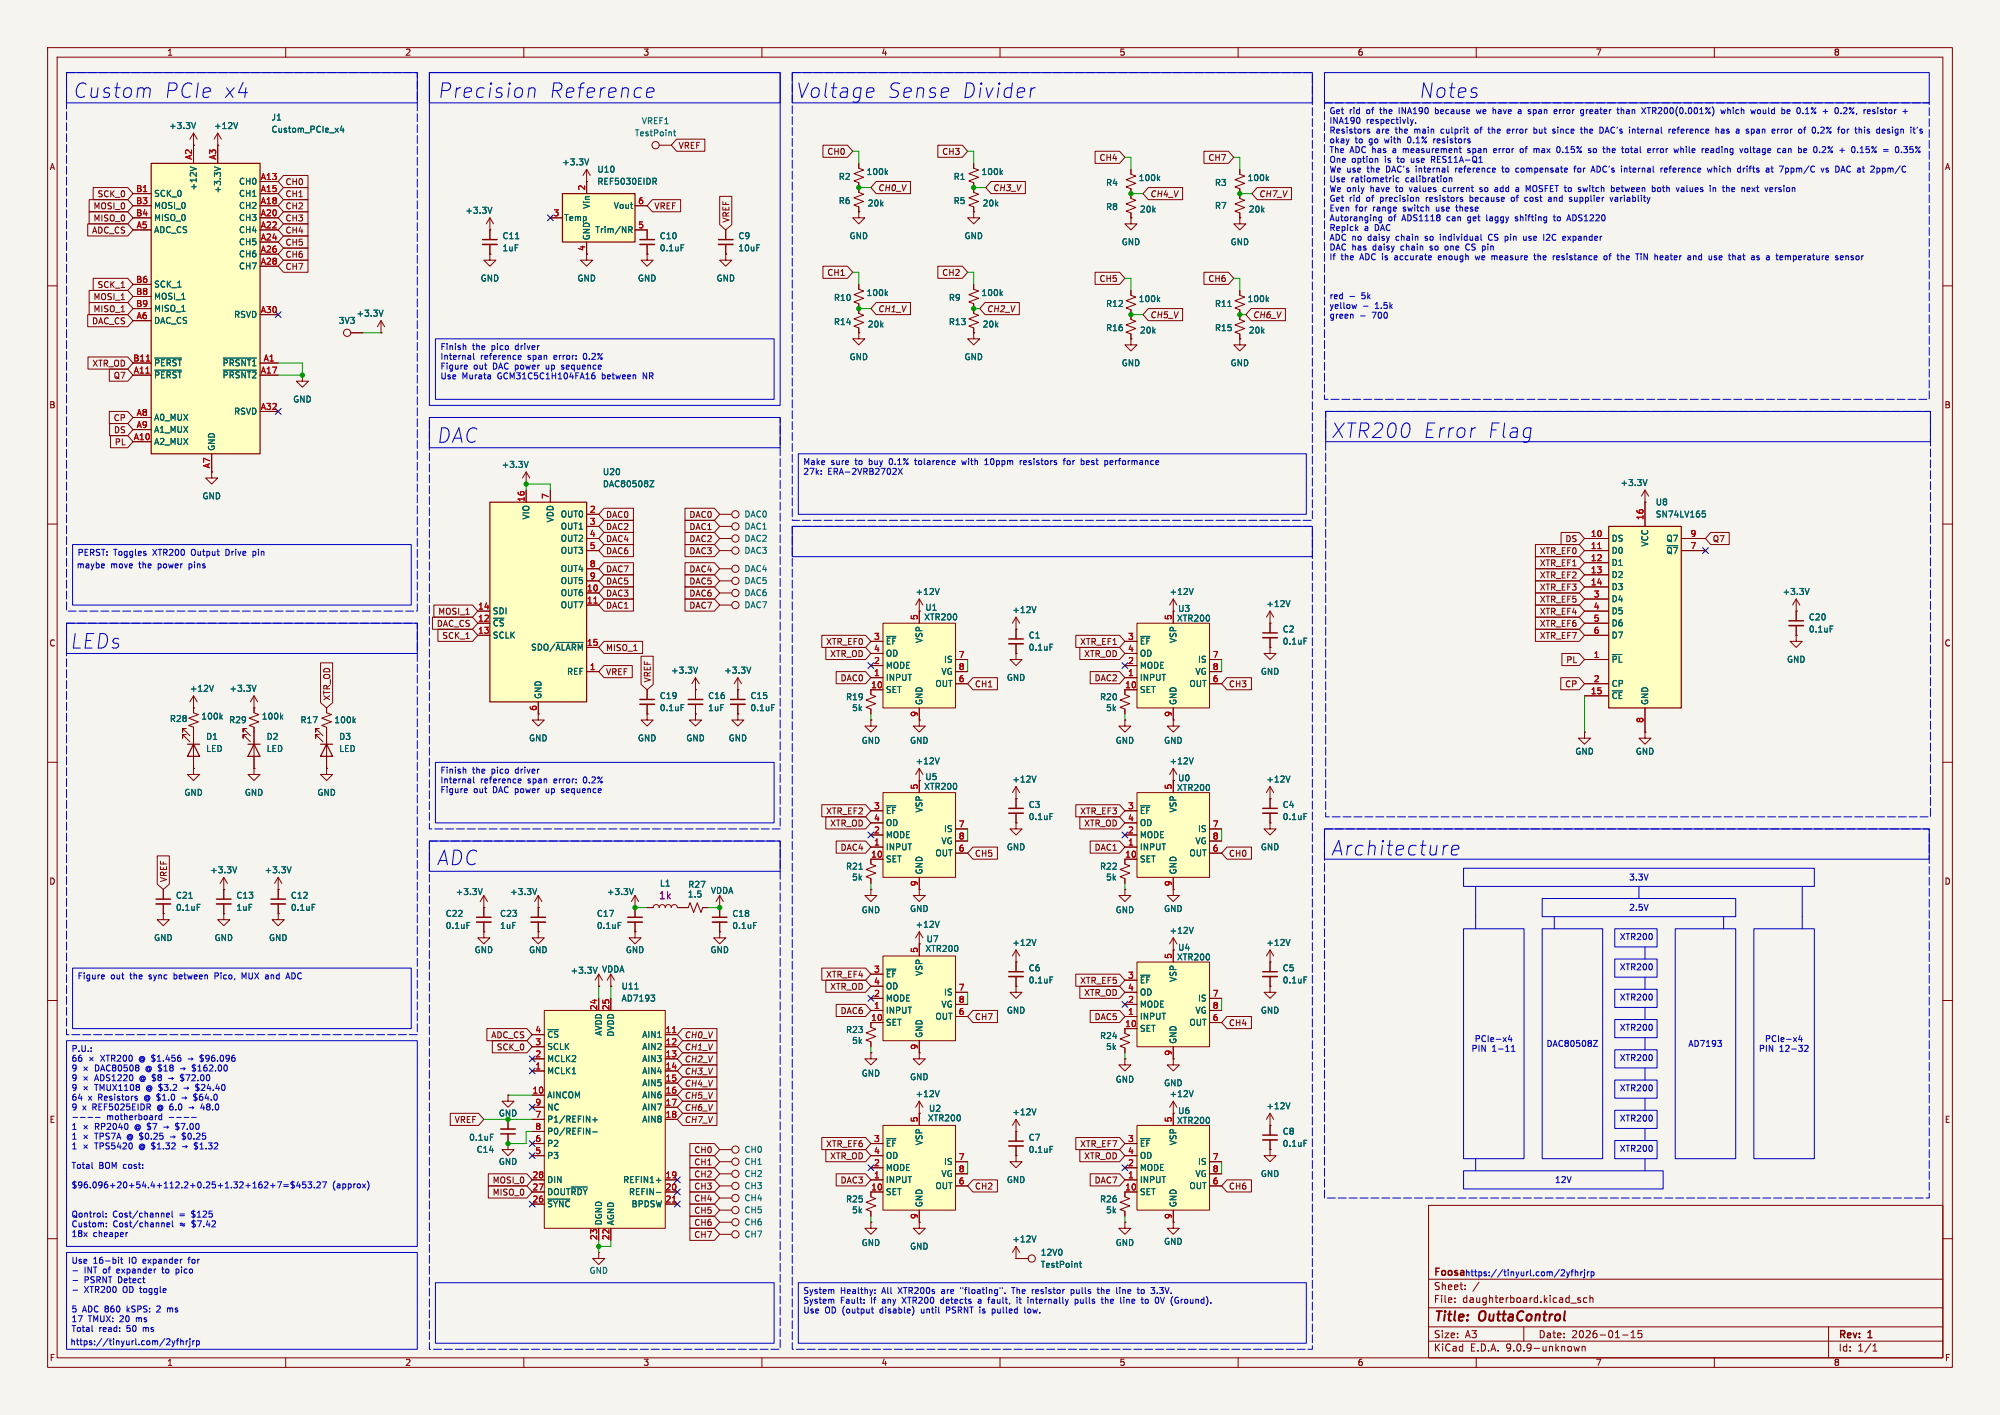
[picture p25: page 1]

4 Vout 6 Trim/NR 5 GND

Finish the pico driver

PERST: Toggles XTR200 Output Drive pin
maybe move the power pins

IS 7 VG 8 OUT 6 VSP

Figure out DAC power up sequence P.U.: 66 þÿ×XTR200 @ $1.456 þÿ!’$96.096

PCIe-x4 PIN 1-11 Figure out the sync between Pico, MUX and ADC

0.1uF GND

- INT of expander to pico
- PSRNT Detect - XTR200 OD toggle

Id: 1/1 Title: OuttaControl File: daughterboard.kicad_sch Sheet: / Foosa

5 ADC 860 kSPS: 2 ms 17 TMUX: 20 ms Total read: 50 ms

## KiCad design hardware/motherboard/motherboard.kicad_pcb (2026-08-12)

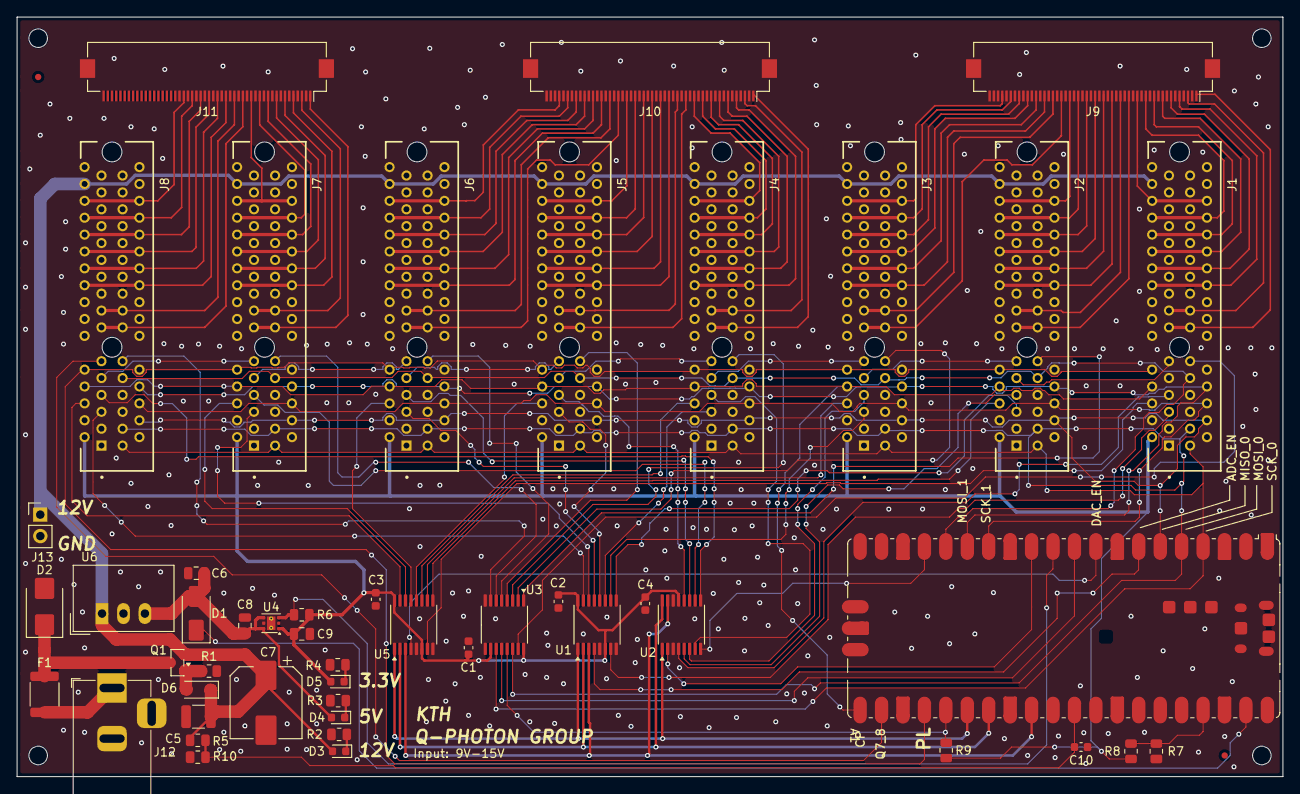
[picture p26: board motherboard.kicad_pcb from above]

Board: 4 copper layers, 150.0 x 90.0 mm, 50 parts (0 on the bottom side), 135 nets.

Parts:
A1: RaspberryPi_Pico; RaspberryPi_Pico_SMD
C1, C2, C3, C4, C10: 0.1uF; C_0603_1608Metric
C5: 10uF; C_1210_3225Metric
C6: 22uF; C_0805_2012Metric
C7: 220uF; CP_Elec_8x10
C8, C9: 10uF; C_0805_2012Metric
D1: SS34; D_SMA
D2: SMBJ16A; D_SMB
D3, D4, D5: LED; LED_0603_1608Metric
D6: BZT52C18; D_SOD-123
F1: 1812L150/24MR; Fuse_1812_4532Metric
FID1, FID2: Fiducial; Fiducial_0.75mm_Mask1.5mm
J1, J2, J3, J4, J5, J6, J7, J8: PCIE-064-02-F-D-TH; SAMTEC_PCIE-064-02-X-D-TH
J9, J10, J11: Conn_01x50_MountingPin; Hirose_FH12-50S-0.5SH_1x50-1MP_P0.50mm_Horizontal
J12: Barrel_Jack_Switch_Pin3Ring; BarrelJack_Horizontal
J13: Conn_01x02_Pin; PinHeader_1x02_P2.54mm_Vertical
Q1: AO3407A; SOT-23
R1, R5, R6: 100k; R_0805_2012Metric
R2, R8: 4.7k; R_0805_2012Metric
R3: 1.5k; R_0805_2012Metric
R4: 680; R_0805_2012Metric
R7, R9: 10k; R_0805_2012Metric
R10: 22k; R_0805_2012Metric
U1, U5: SN74HC138PWR; TSSOP-16_4.4x5mm_P0.65mm
U2: TMUX1208PW; TSSOP-16_4.4x5mm_P0.65mm
U3: SN74LV595; TSSOP-16_4.4x5mm_P0.65mm
U4: LP5912-3.3DRV; WSON-6-1EP_2x2mm_P0.65mm_EP1x1.6mm_ThermalVias
U6: K7805-500R3; Converter_DCDC_TRACO_TSR-1_THT

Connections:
3V3_EN: A1.37 (3V3_EN), R7.2, R8.1
12V_SENSE: A1.31 (GPIO26_ADC0), C10.1, R5.2, R10.1
+3.3V: C1.1, C2.1, C3.1, C4.1, C9.1, D5.2 (A), J1.A2 (+3.3V), J2.A2 (+3.3V), J3.A2 (+3.3V), J4.A2 (+3.3V), J5.A2 (+3.3V), J6.A2 (+3.3V), J7.A2 (+3.3V), J8.A2 (+3.3V), R6.1, R8.2, R9.2, U1.6 (E2), U1.16 (VCC), U2.13 (VDD), U3.10 (~SRCLR), U3.16 (VCC), U4.1 (OUT), U5.6 (E2), U5.16 (VCC)
+5V: C6.1, C8.1, D1.2 (A), D4.2 (A), U4.4 (EN), U4.6 (IN), U6.3 (Vout)
+12V: C5.1, C7.1, D3.2 (A), D6.1 (K), J1.A30 (+12V), J2.A30 (+12V), J3.A30 (+12V), J4.A30 (+12V), J5.A30 (+12V), J6.A30 (+12V), J7.A30 (+12V), J8.A30 (+12V), J13.1, Q1.2 (S), R5.1, U6.1 (Vin)
A1: A1.26 (GPIO20), U1.1 (A0), U2.1 (A0), U5.1 (A0)
A2: A1.27 (GPIO21), U1.2 (A1), U2.16 (A1), U5.2 (A1)
A3: A1.29 (GPIO22), U1.3 (A2), U2.15 (A2), U5.3 (A2)
ADC_CS1: J1.A5 (ADC_CS), U1.7 (~Y7)
ADC_CS2: J2.A5 (ADC_CS), U1.9 (~Y6)
ADC_CS3: J3.A5 (ADC_CS), U1.10 (~Y5)
ADC_CS4: J4.A5 (ADC_CS), U1.11 (~Y4)
ADC_CS5: J5.A5 (ADC_CS), U1.12 (~Y3)
ADC_CS6: J6.A5 (ADC_CS), U1.13 (~Y2)
ADC_CS7: J7.A5 (ADC_CS), U1.14 (~Y1)
ADC_CS8: J8.A5 (ADC_CS), U1.15 (~Y0)
ADC_EN: A1.7 (GPIO5), U1.4 (~E0)
AT1: J1.A7 (AT), U2.4 (S1)
AT2: J2.A7 (AT), U2.5 (S2)
AT3: J3.A7 (AT), U2.6 (S3)
AT4: J4.A7 (AT), U2.7 (S4)
AT5: J5.A7 (AT), U2.12 (S5)
AT6: J6.A7 (AT), U2.11 (S6)
AT7: J7.A7 (AT), U2.10 (S7)
AT8: J8.A7 (AT), U2.9 (S8)
AT_EN: A1.12 (GPIO9), U2.2 (EN)
AT_MUX: A1.17 (GPIO13), U2.8 (D)
CH0: J1.A13 (CH0), J1.B13 (CH0), J9.1
CH1: J1.A15 (CH1), J1.B15 (CH1), J9.3
CH2: J1.A18 (CH2), J1.B18 (CH2), J9.5
CH3: J1.A20 (CH3), J1.B20 (CH3), J9.7
CH4: J1.A22 (CH4), J1.B22 (CH4), J9.9
CH5: J1.A24 (CH5), J1.B24 (CH5), J9.11
CH6: J1.A26 (CH6), J1.B26 (CH6), J9.13
CH7: J1.A28 (CH7), J1.B28 (CH7), J9.15
CH8: J2.A13 (CH0), J2.B13 (CH0), J9.17
CH9: J2.A15 (CH1), J2.B15 (CH1), J9.19
CH10: J2.A18 (CH2), J2.B18 (CH2), J9.21
CH11: J2.A20 (CH3), J2.B20 (CH3), J9.23
CH12: J2.A22 (CH4), J2.B22 (CH4), J9.25
CH13: J2.A24 (CH5), J2.B24 (CH5), J9.27
CH14: J2.A26 (CH6), J2.B26 (CH6), J9.29
CH15: J2.A28 (CH7), J2.B28 (CH7), J9.31
CH16: J3.A13 (CH0), J3.B13 (CH0), J9.33
CH17: J3.A15 (CH1), J3.B15 (CH1), J9.35
CH18: J3.A18 (CH2), J3.B18 (CH2), J9.37
CH19: J3.A20 (CH3), J3.B20 (CH3), J9.39
CH20: J3.A22 (CH4), J3.B22 (CH4), J9.41
CH21: J3.A24 (CH5), J3.B24 (CH5), J9.43
CH22: J3.A26 (CH6), J3.B26 (CH6), J9.45
CH23: J3.A28 (CH7), J3.B28 (CH7), J9.47
CH24: J4.A13 (CH0), J4.B13 (CH0), J10.1
CH25: J4.A15 (CH1), J4.B15 (CH1), J10.3
CH26: J4.A18 (CH2), J4.B18 (CH2), J10.5
CH27: J4.A20 (CH3), J4.B20 (CH3), J10.7
CH28: J4.A22 (CH4), J4.B22 (CH4), J10.9
CH29: J4.A24 (CH5), J4.B24 (CH5), J10.11
CH30: J4.A26 (CH6), J4.B26 (CH6), J10.13
CH31: J4.A28 (CH7), J4.B28 (CH7), J10.15
CH32: J5.A13 (CH0), J5.B13 (CH0), J10.17
CH33: J5.A15 (CH1), J5.B15 (CH1), J10.19
CH34: J5.A18 (CH2), J5.B18 (CH2), J10.21
CH35: J5.A20 (CH3), J5.B20 (CH3), J10.23
CH36: J5.A22 (CH4), J5.B22 (CH4), J10.25
CH37: J5.A24 (CH5), J5.B24 (CH5), J10.27
CH38: J5.A26 (CH6), J5.B26 (CH6), J10.29
CH39: J5.A28 (CH7), J5.B28 (CH7), J10.31
CH40: J6.A13 (CH0), J6.B13 (CH0), J10.33
CH41: J6.A15 (CH1), J6.B15 (CH1), J10.35
CH42: J6.A18 (CH2), J6.B18 (CH2), J10.37
CH43: J6.A20 (CH3), J6.B20 (CH3), J10.39
CH44: J6.A22 (CH4), J6.B22 (CH4), J10.41
CH45: J6.A24 (CH5), J6.B24 (CH5), J10.43
CH46: J6.A26 (CH6), J6.B26 (CH6), J10.45
CH47: J6.A28 (CH7), J6.B28 (CH7), J10.47
CH48: J7.A13 (CH0), J7.B13 (CH0), J11.1
CH49: J7.A15 (CH1), J7.B15 (CH1), J11.3
CH50: J7.A18 (CH2), J7.B18 (CH2), J11.5
CH51: J7.A20 (CH3), J7.B20 (CH3), J11.7
CH52: J7.A22 (CH4), J7.B22 (CH4), J11.9
CH53: J7.A24 (CH5), J7.B24 (CH5), J11.11
CH54: J7.A26 (CH6), J7.B26 (CH6), J11.13
CH55: J7.A28 (CH7), J7.B28 (CH7), J11.15
CH56: J8.A13 (CH0), J8.B13 (CH0), J11.17
CH57: J8.A15 (CH1), J8.B15 (CH1), J11.19
CH58: J8.A18 (CH2), J8.B18 (CH2), J11.21
CH59: J8.A20 (CH3), J8.B20 (CH3), J11.23
CH60: J8.A22 (CH4), J8.B22 (CH4), J11.25
CH61: J8.A24 (CH5), J8.B24 (CH5), J11.27
CH62: J8.A26 (CH6), J8.B26 (CH6), J11.29
CH63: J8.A28 (CH7), J8.B28 (CH7), J11.31
CP: A1.21 (GPIO16), J1.A8 (A0_MUX), J2.A8 (A0_MUX), J3.A8 (A0_MUX), J4.A8 (A0_MUX), J5.A8 (A0_MUX), J6.A8 (A0_MUX), J7.A8 (A0_MUX), J8.A8 (A0_MUX)
DAC_CS1: J1.A6 (DAC_CS), U5.7 (~Y7)
DAC_CS2: J2.A6 (DAC_CS), U5.9 (~Y6)
DAC_CS3: J3.A6 (DAC_CS), U5.10 (~Y5)
DAC_CS4: J4.A6 (DAC_CS), U5.11 (~Y4)
DAC_CS5: J5.A6 (DAC_CS), U5.12 (~Y3)
DAC_CS6: J6.A6 (DAC_CS), U5.13 (~Y2)
DAC_CS7: J7.A6 (DAC_CS), U5.14 (~Y1)
DAC_CS8: J8.A6 (DAC_CS), U5.15 (~Y0)
DAC_EN: A1.9 (GPIO6), U5.4 (~E0)
GND: A1.3 (GND), A1.8 (GND), A1.13 (GND), A1.18 (GND), A1.23 (GND), A1.28 (GND), A1.33 (AGND), A1.38 (GND), A1.D2 (GND), C1.2, C2.2, C3.2, C4.2, C5.2, C6.2, C7.2, C8.2, C9.2, C10.2, D2.2 (A2), J1.A1 (~PRSNT1), J1.A3 (GND), J1.A4 (GND), J1.A9 (A1_MUX), J1.A12 (GND), J1.A14 (CH0), J1.A16 (CH1), J1.A17 (GND), J1.A19 (CH2), J1.A21 (CH3), J1.A23 (CH4), J1.A25 (CH5), J1.A27 (CH6), J1.A29 (CH7), J1.A31 (GND), J1.B2 (GND), J1.B5 (GND), J1.B7 (GND), J1.B10 (GND), J1.B12 (GND), J1.B14 (CH0), J1.B16 (CH1), J1.B19 (CH2), J1.B21 (CH3), J1.B23 (CH4), J1.B25 (CH5), J1.B27 (CH6), J1.B29 (CH7), J1.B31 (~PRSNT2), J1.B32 (GND), J2.A1 (~PRSNT1), J2.A3 (GND), J2.A4 (GND), J2.A12 (GND), J2.A14 (CH0), J2.A16 (CH1), J2.A17 (GND), J2.A19 (CH2), J2.A21 (CH3), J2.A23 (CH4), J2.A25 (CH5), J2.A27 (CH6), J2.A29 (CH7), J2.A31 (GND), J2.B2 (GND), J2.B5 (GND), J2.B7 (GND), J2.B10 (GND), J2.B12 (GND), J2.B14 (CH0), J2.B16 (CH1), J2.B19 (CH2), J2.B21 (CH3), J2.B23 (CH4), J2.B25 (CH5), J2.B27 (CH6), J2.B29 (CH7), J2.B31 (~PRSNT2), J2.B32 (GND), J3.A1 (~PRSNT1), J3.A3 (GND), J3.A4 (GND), J3.A12 (GND), J3.A14 (CH0), J3.A16 (CH1), J3.A17 (GND), J3.A19 (CH2), J3.A21 (CH3), J3.A23 (CH4), J3.A25 (CH5), J3.A27 (CH6), J3.A29 (CH7), J3.A31 (GND), J3.B2 (GND), J3.B5 (GND), J3.B7 (GND), J3.B10 (GND), J3.B12 (GND), J3.B14 (CH0), J3.B16 (CH1), J3.B19 (CH2), J3.B21 (CH3), J3.B23 (CH4), J3.B25 (CH5), J3.B27 (CH6), J3.B29 (CH7), J3.B31 (~PRSNT2), J3.B32 (GND), J4.A1 (~PRSNT1), J4.A3 (GND), J4.A4 (GND), J4.A12 (GND), J4.A14 (CH0), J4.A16 (CH1), J4.A17 (GND), J4.A19 (CH2), J4.A21 (CH3), J4.A23 (CH4), J4.A25 (CH5), J4.A27 (CH6), J4.A29 (CH7), J4.A31 (GND), J4.B2 (GND), J4.B5 (GND), J4.B7 (GND), J4.B10 (GND), J4.B12 (GND), J4.B14 (CH0), J4.B16 (CH1), J4.B19 (CH2), J4.B21 (CH3), J4.B23 (CH4), J4.B25 (CH5), J4.B27 (CH6), J4.B29 (CH7), J4.B31 (~PRSNT2), J4.B32 (GND), J5.A1 (~PRSNT1), J5.A3 (GND), J5.A4 (GND), J5.A12 (GND), J5.A14 (CH0), J5.A16 (CH1), J5.A17 (GND), J5.A19 (CH2), J5.A21 (CH3), J5.A23 (CH4), J5.A25 (CH5), J5.A27 (CH6), J5.A29 (CH7), J5.A31 (GND), J5.B2 (GND), J5.B5 (GND), J5.B7 (GND), J5.B10 (GND), J5.B12 (GND), J5.B14 (CH0), J5.B16 (CH1), J5.B19 (CH2), J5.B21 (CH3), J5.B23 (CH4), J5.B25 (CH5), J5.B27 (CH6), J5.B29 (CH7), J5.B31 (~PRSNT2), J5.B32 (GND), J6.A1 (~PRSNT1), J6.A3 (GND), J6.A4 (GND), J6.A12 (GND), J6.A14 (CH0), J6.A16 (CH1), J6.A17 (GND), J6.A19 (CH2), J6.A21 (CH3), J6.A23 (CH4), J6.A25 (CH5)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
MISO_0: A1.6 (GPIO4), J1.B4 (MISO_0), J2.B4 (MISO_0), J3.B4 (MISO_0), J4.B4 (MISO_0), J5.B4 (MISO_0), J6.B4 (MISO_0), J7.B4 (MISO_0), J8.B4 (MISO_0)
MISO_1: A1.16 (GPIO12), J1.B9 (MISO_1), J2.B9 (MISO_1), J3.B9 (MISO_1), J4.B9 (MISO_1), J5.B9 (MISO_1), J6.B9 (MISO_1), J7.B9 (MISO_1), J8.B9 (MISO_1)
MOSI_0: A1.5 (GPIO3), J1.B3 (MOSI_0), J2.B3 (MOSI_0), J3.B3 (MOSI_0), J4.B3 (MOSI_0), J5.B3 (MOSI_0), J6.B3 (MOSI_0), J7.B3 (MOSI_0), J8.B3 (MOSI_0), U3.14 (SER)
MOSI_1: A1.15 (GPIO11), J1.B8 (MOSI_1), J2.B8 (MOSI_1), J3.B8 (MOSI_1), J4.B8 (MOSI_1), J5.B8 (MOSI_1), J6.B8 (MOSI_1), J7.B8 (MOSI_1), J8.B8 (MOSI_1)
unnamed: D2.1 (A1), F1.1, Q1.3 (D)
unnamed: D3.1 (K), R2.2
unnamed: D4.1 (K), R3.2
unnamed: D5.1 (K), R4.2
unnamed: D6.2 (A), Q1.1 (G), R1.1
PG: A1.11 (GPIO8), R6.2, U4.3 (PG)
PL: A1.24 (GPIO18), J1.A10 (A2_MUX), J2.A10 (A2_MUX), J3.A10 (A2_MUX), J4.A10 (A2_MUX), J5.A10 (A2_MUX), J6.A10 (A2_MUX), J7.A10 (A2_MUX), J8.A10 (A2_MUX)
Q7_1: J1.A11 (~PERST), J2.A9 (A1_MUX)
Q7_2: J2.A11 (~PERST), J3.A9 (A1_MUX)
Q7_3: J3.A11 (~PERST), J4.A9 (A1_MUX)
Q7_4: J4.A11 (~PERST), J5.A9 (A1_MUX)
Q7_5: J5.A11 (~PERST), J6.A9 (A1_MUX)
Q7_6: J6.A11 (~PERST), J7.A9 (A1_MUX)
Q7_7: J7.A11 (~PERST), J8.A9 (A1_MUX)
Q7_8: A1.22 (GPIO17), J8.A11 (~PERST)
SCK_0: A1.4 (GPIO2), J1.B1 (SCK_0), J2.B1 (SCK_0), J3.B1 (SCK_0), J4.B1 (SCK_0), J5.B1 (SCK_0), J6.B1 (SCK_0), J7.B1 (SCK_0), J8.B1 (SCK_0), U3.11 (SRCLK)
SCK_1: A1.14 (GPIO10), J1.B6 (SCK_1), J2.B6 (SCK_1), J3.B6 (SCK_1), J4.B6 (SCK_1), J5.B6 (SCK_1), J6.B6 (SCK_1), J7.B6 (SCK_1), J8.B6 (SCK_1)
VIN_JACK: F1.2, J12.1
VSYS: A1.39 (VSYS), D1.1 (K)
XTR_OD_1: J1.B11 (~PERST), U3.15 (QA)
XTR_OD_2: J2.B11 (~PERST), U3.1 (QB)
XTR_OD_3: J3.B11 (~PERST), U3.2 (QC)
XTR_OD_4: J4.B11 (~PERST), U3.3 (QD)
XTR_OD_5: J5.B11 (~PERST), U3.4 (QE)
XTR_OD_6: J6.B11 (~PERST), U3.5 (QF)
XTR_OD_7: J7.B11 (~PERST), U3.6 (QG)
XTR_OD_8: J8.B11 (~PERST), U3.7 (QH)
XTR_RCLK: A1.10 (GPIO7), U3.12 (RCLK)
~OE: A1.25 (GPIO19), R9.1, U3.13 (~OE)

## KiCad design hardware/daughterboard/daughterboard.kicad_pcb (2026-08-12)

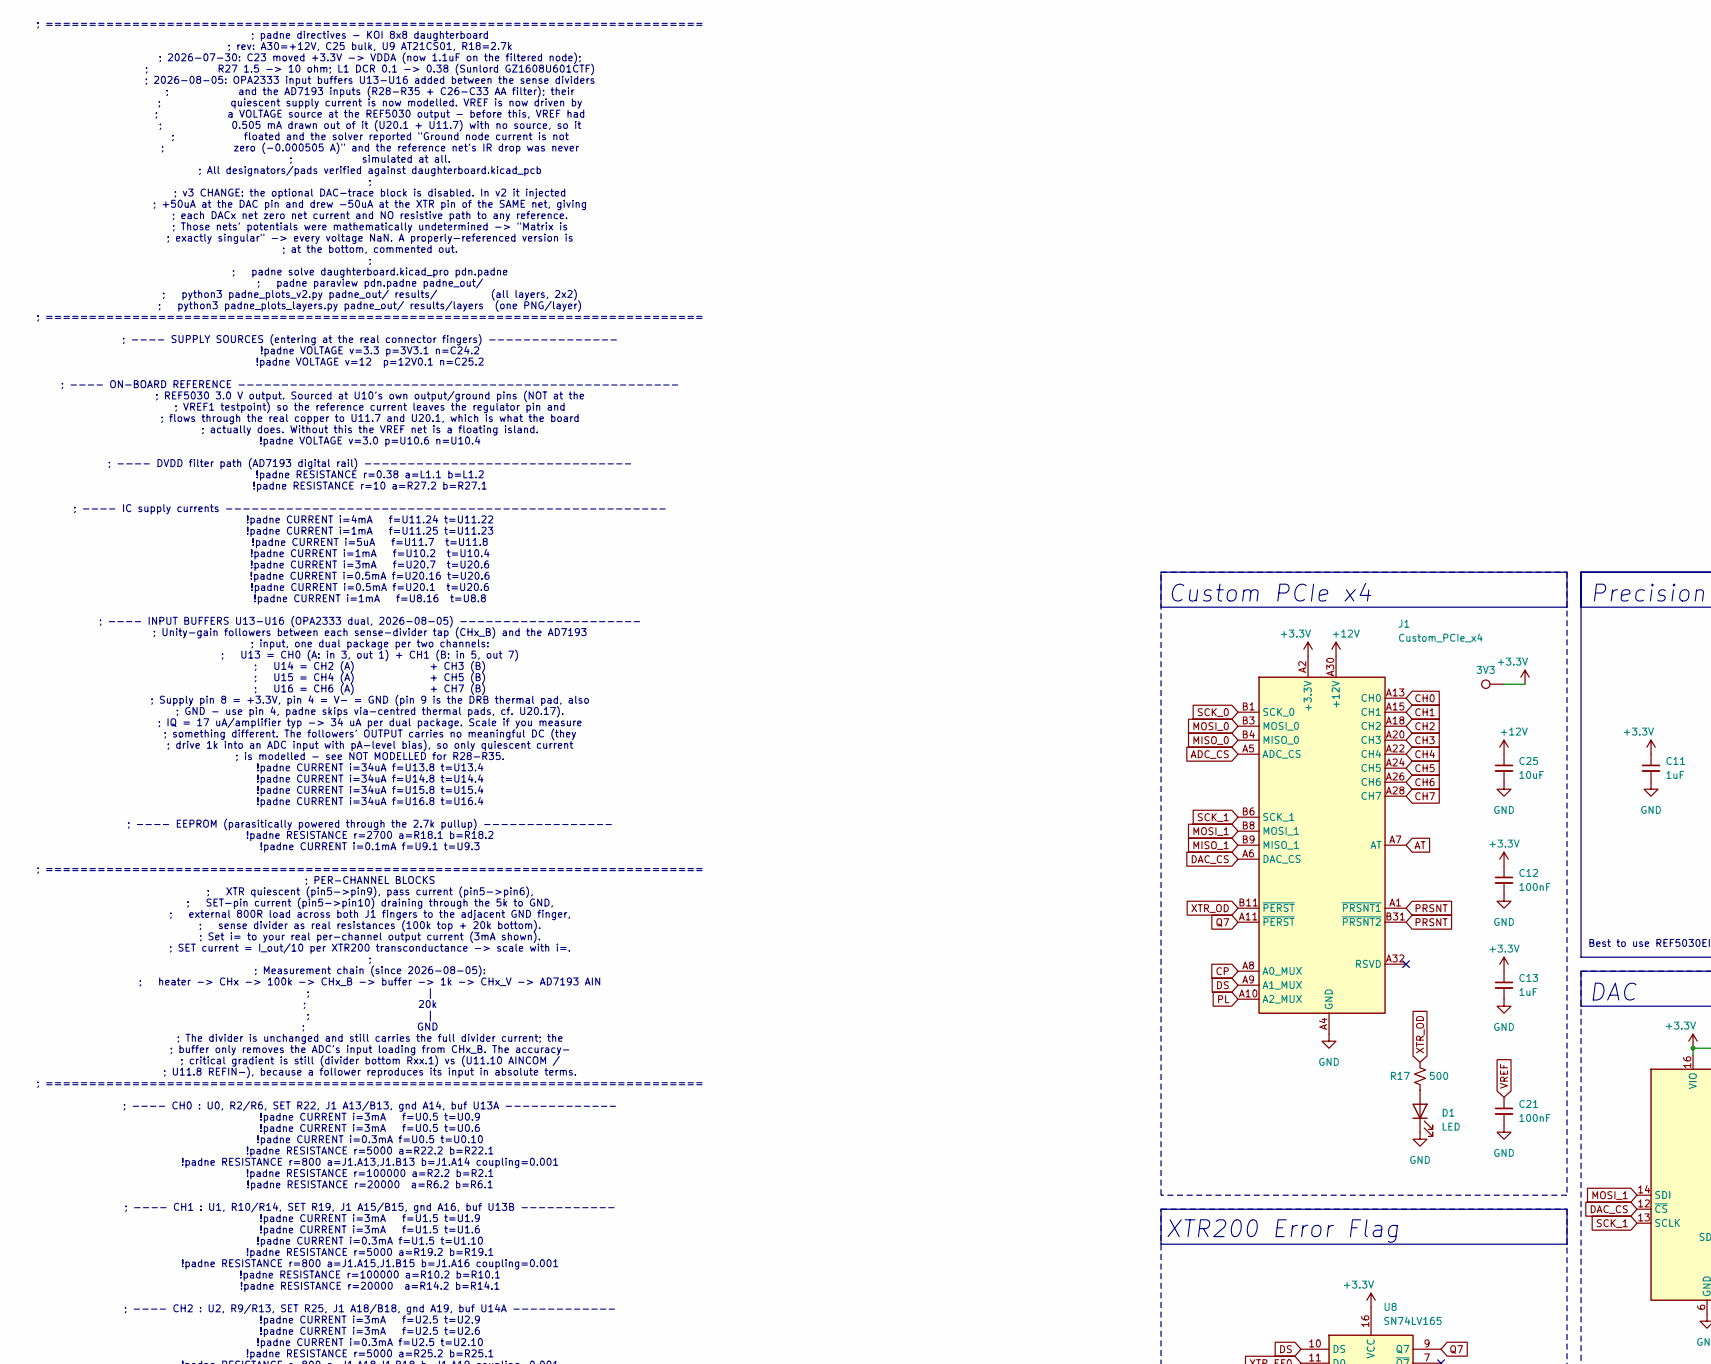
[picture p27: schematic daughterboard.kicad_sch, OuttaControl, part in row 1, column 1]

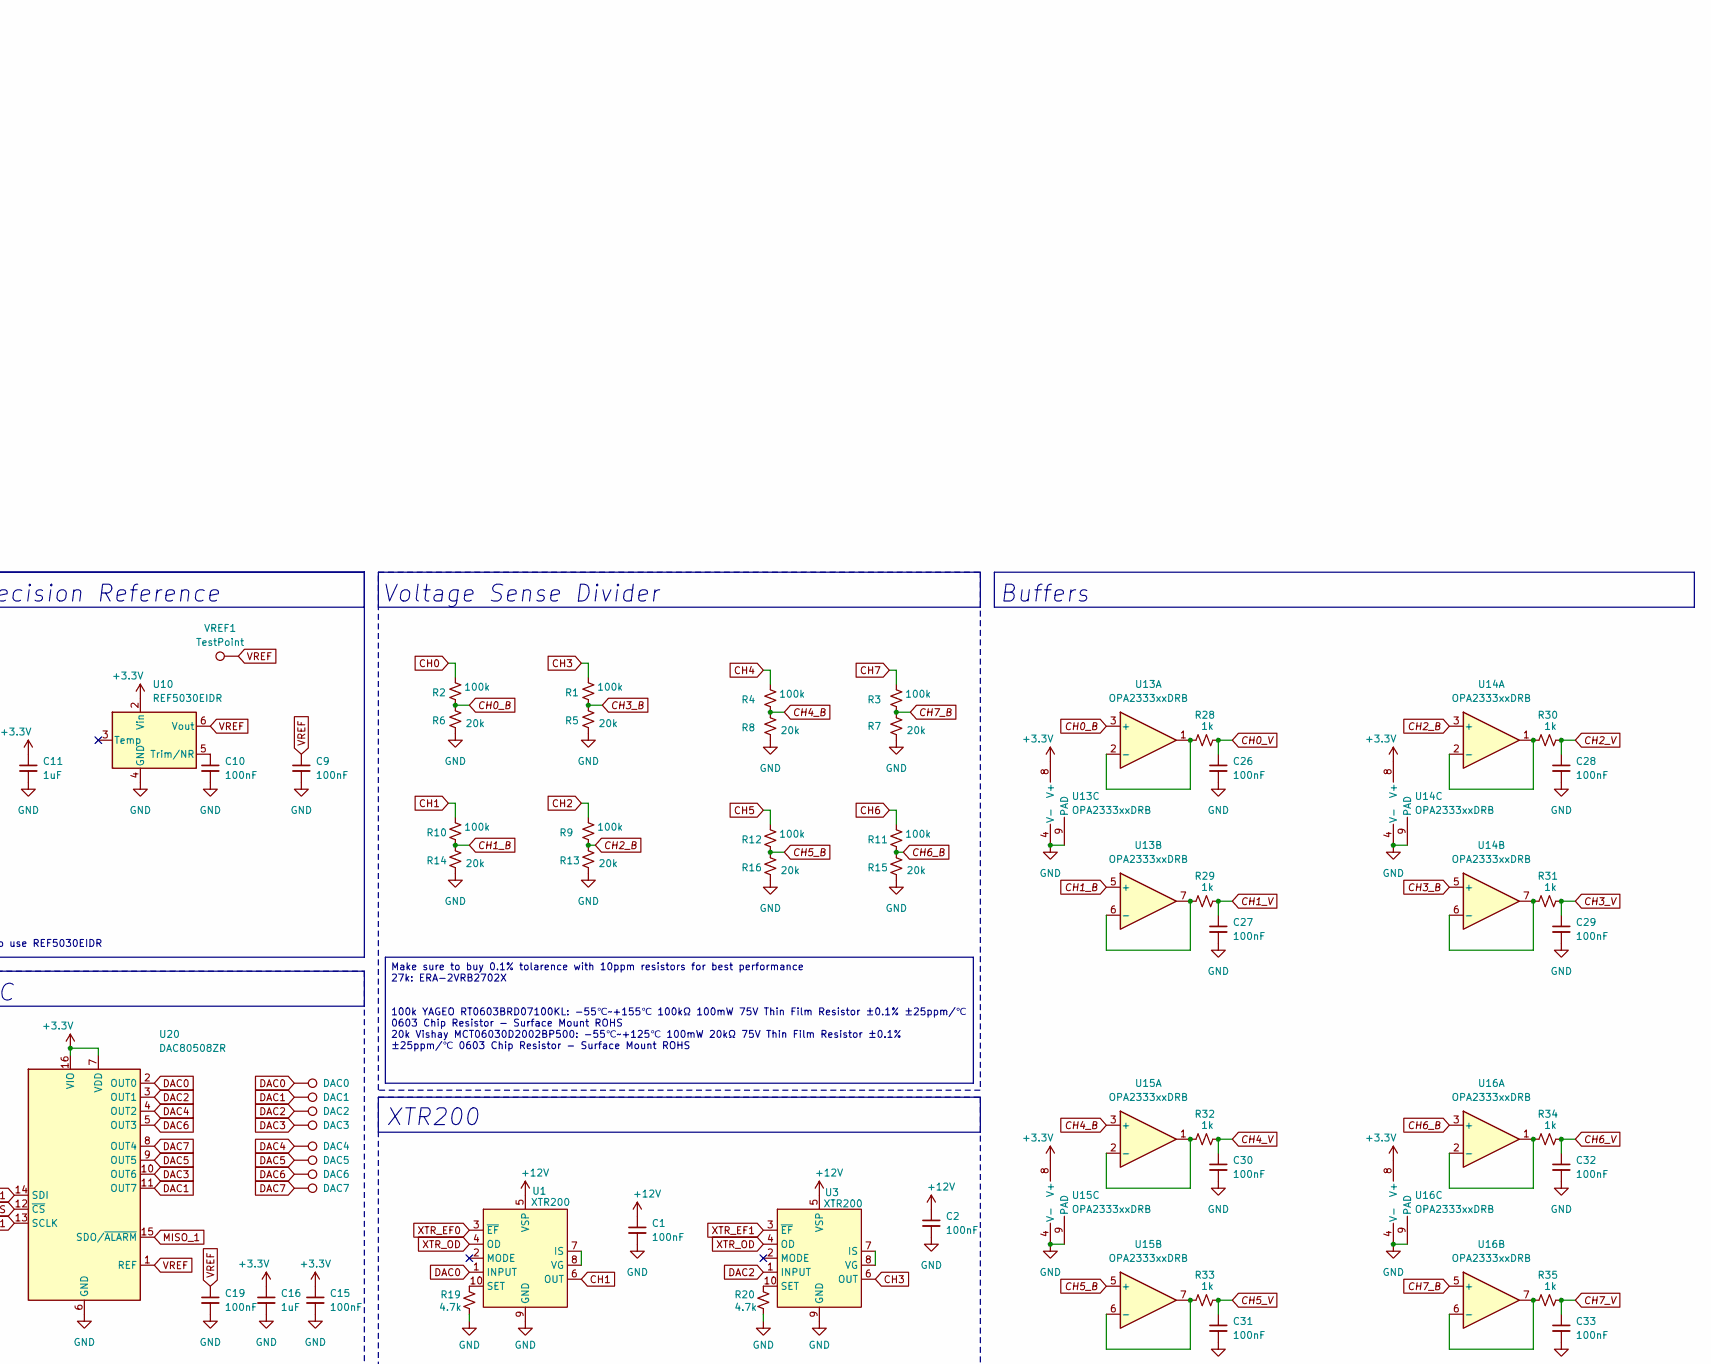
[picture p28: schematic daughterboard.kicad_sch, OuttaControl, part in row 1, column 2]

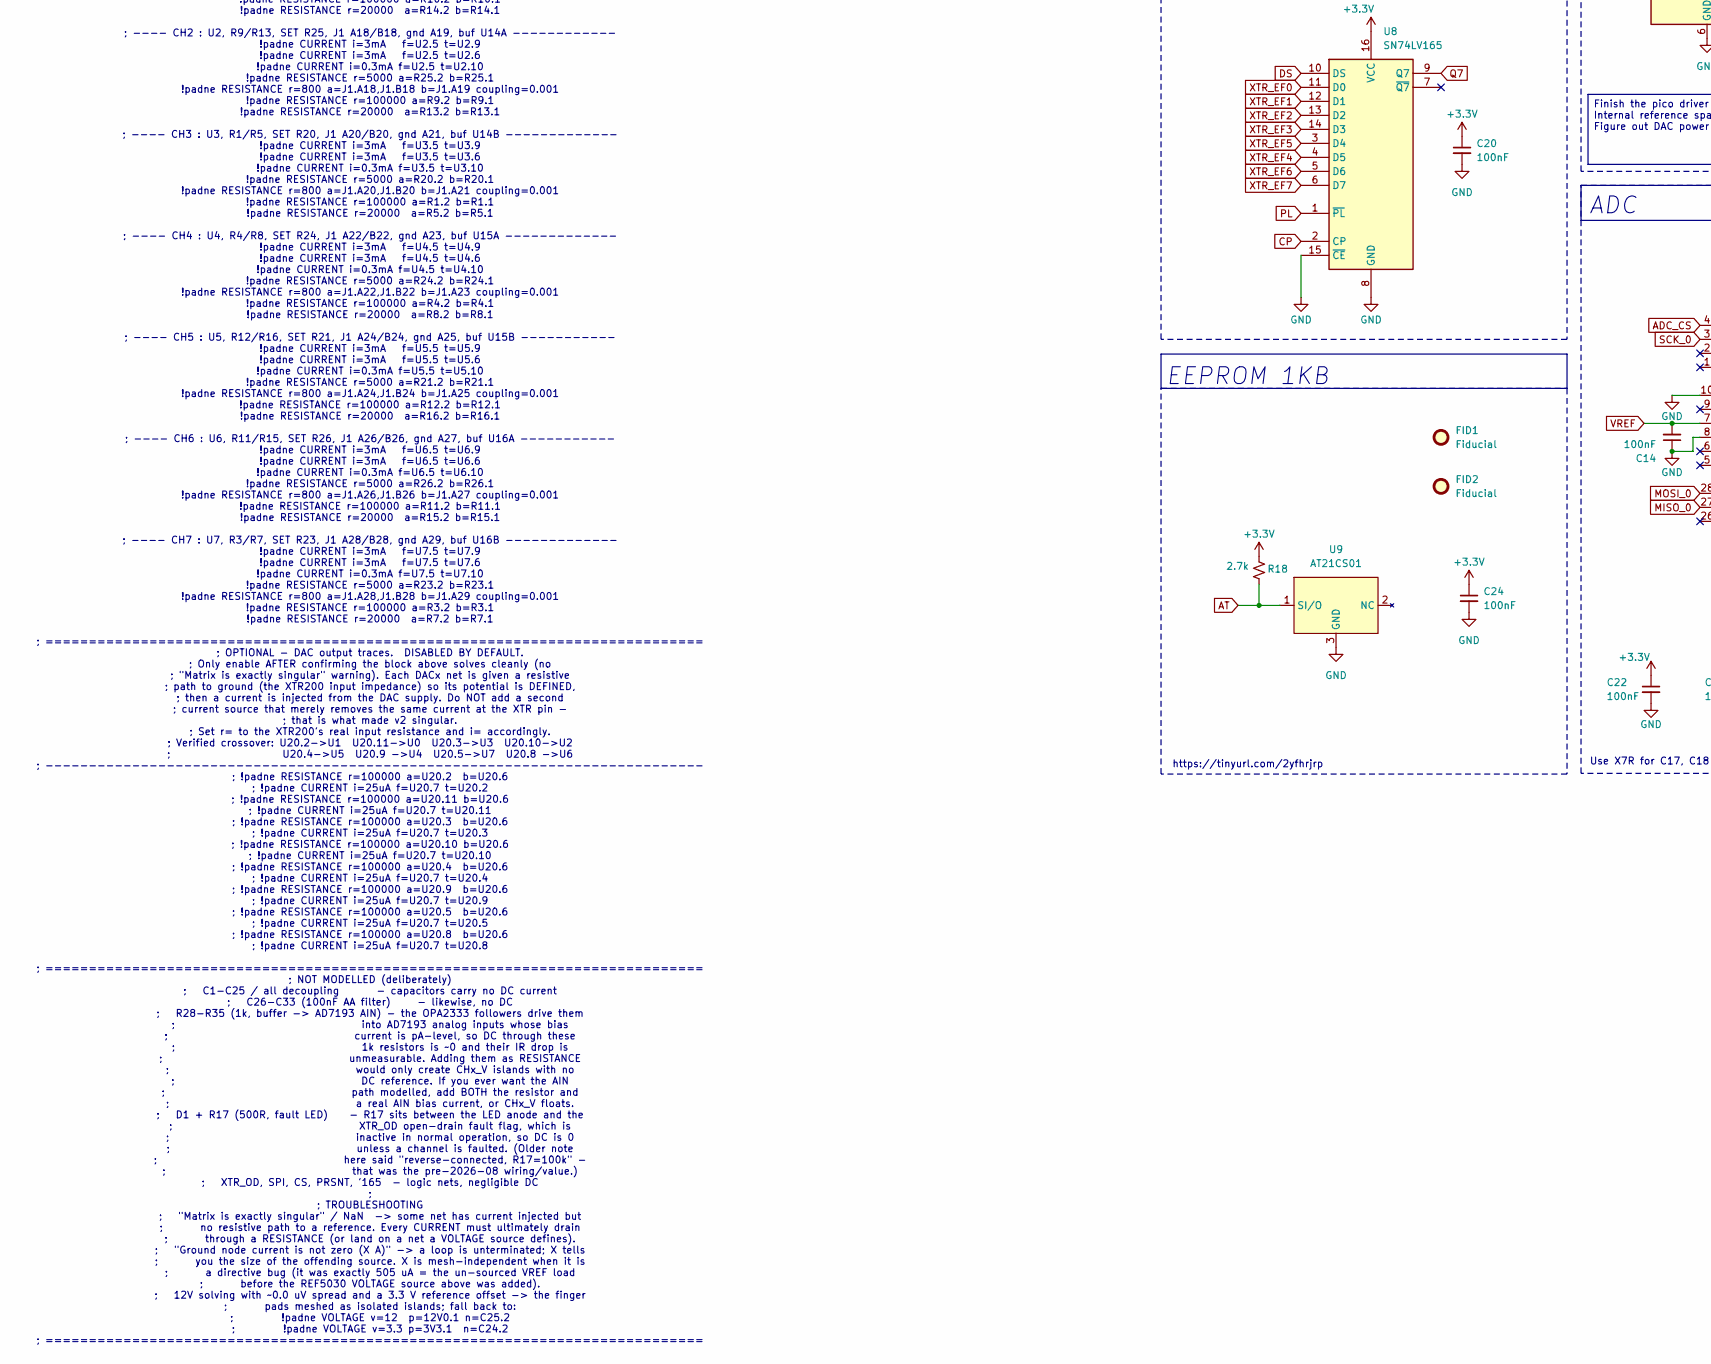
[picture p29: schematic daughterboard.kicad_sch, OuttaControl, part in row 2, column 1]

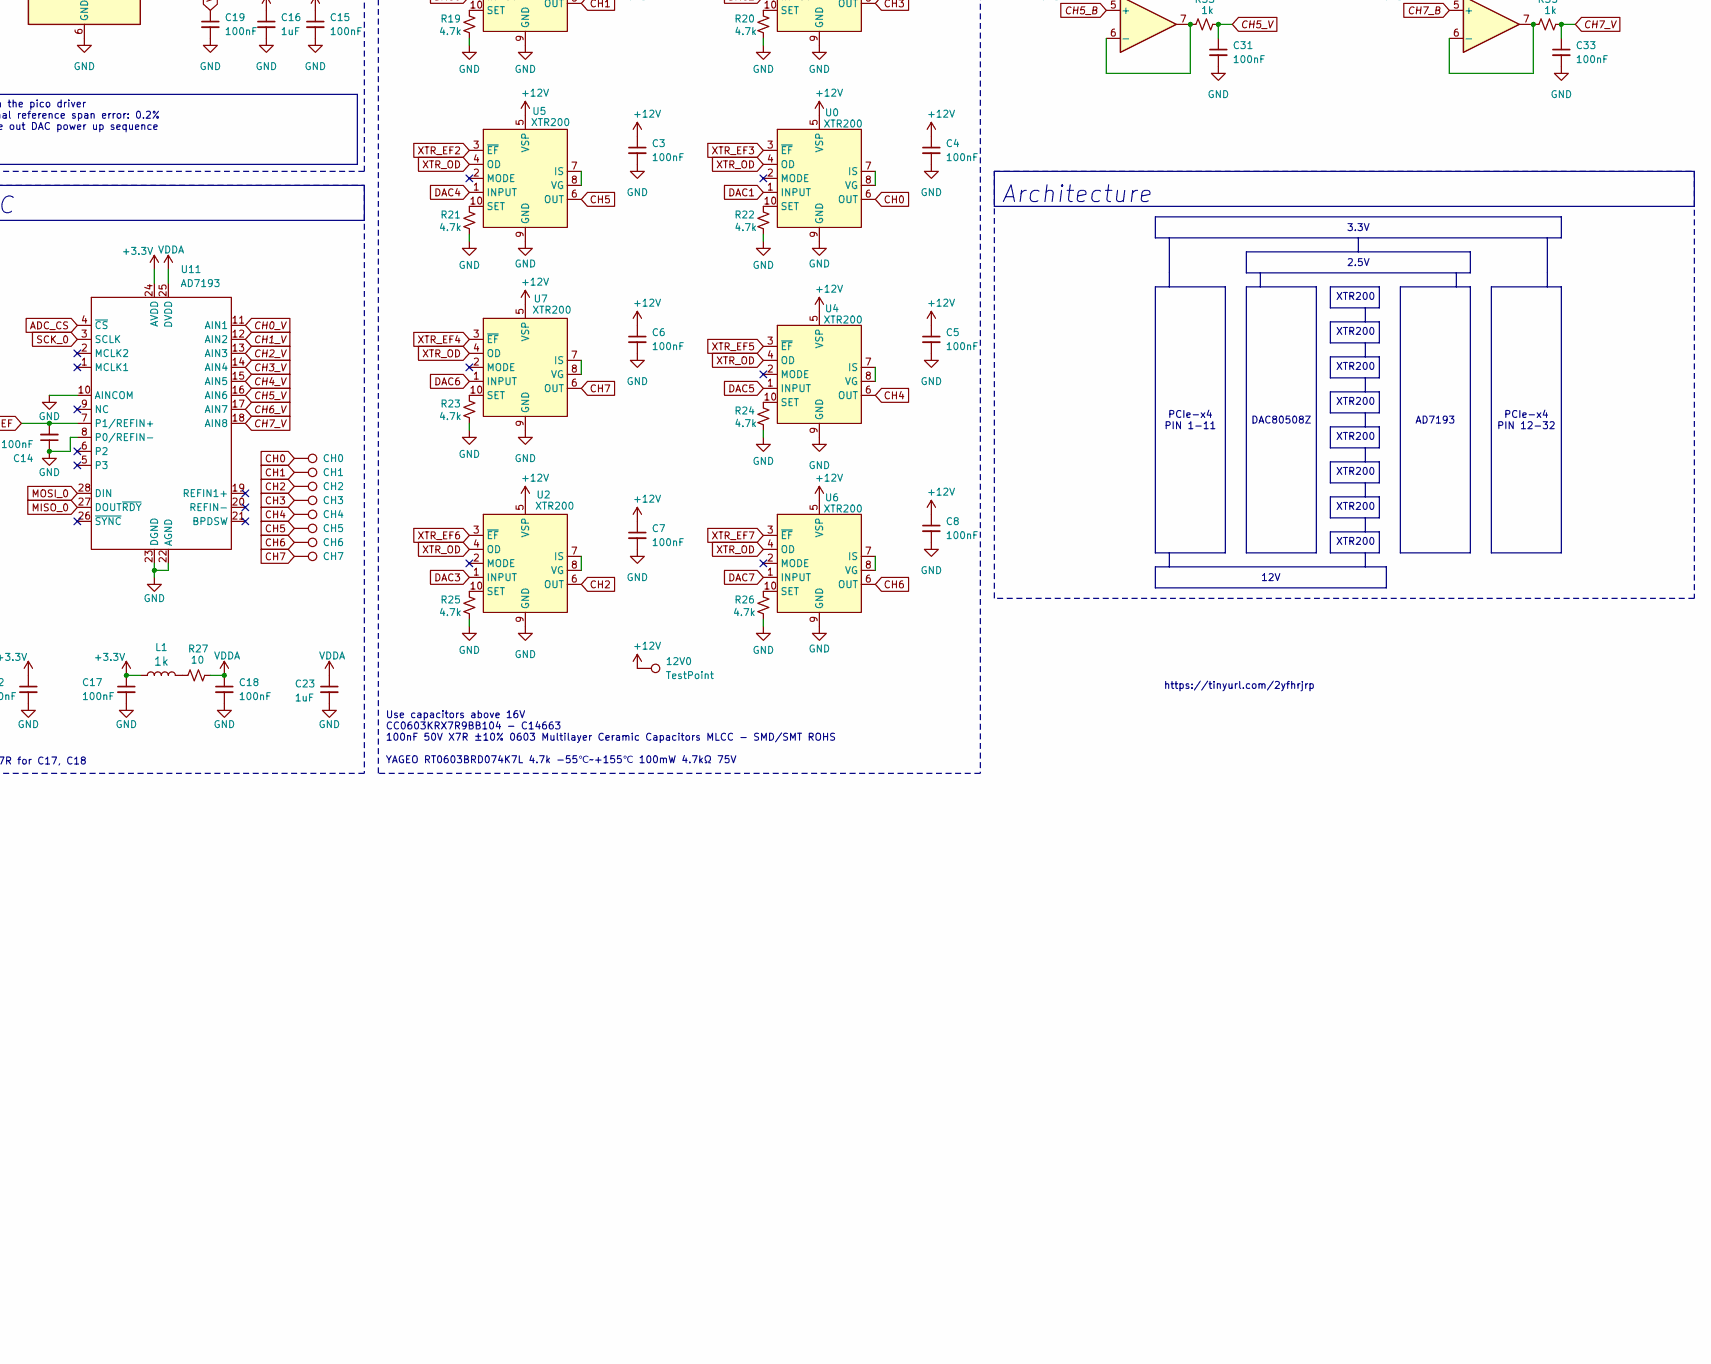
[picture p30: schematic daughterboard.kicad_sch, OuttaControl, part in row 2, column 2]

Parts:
3V3: TestPoint_Pad_D1.0mm
12V0: TestPoint; TestPoint_Pad_D1.0mm
C1, C2, C3, C4, C5, C6, C7, C8, C9, C10, C12, C14, C15, C17, C18, C19, C20, C21, C22, C24, C26, C27, C28, C29, C30, C31, C32, C33: 100nF; C_0603_1608Metric; LCSC C14663
C11, C13, C16, C23: 1uF; C_0603_1608Metric; LCSC C15849
C25: 10uF; C_0603_1608Metric; LCSC C96446
CH0, CH1, CH2, CH3, CH4, CH5, CH6, CH7: TestPoint_Pad_D1.0mm
D1: LED; LED_0603_1608Metric; LCSC C125114
DAC0, DAC1, DAC2, DAC3, DAC4, DAC5, DAC6, DAC7: TestPoint_Pad_D1.0mm
FID1, FID2: Fiducial; Fiducial_1mm_Mask2mm
J1: Custom_PCIe_x4; Custom_BUS_PCIexpress_x4
L1: FerriteBead_0603_1.5A; L_0603_1608Metric; Part Number FCM1608KF-601T05; LCSC C133937
R1, R2, R3, R4, R9, R10, R11, R12: 100k; R_0603_1608Metric; LCSC C122538
R5, R6, R7, R8, R13, R14, R15, R16: 20k; R_0603_1608Metric; LCSC C154077
R17: 500; R_0603_1608Metric; LCSC C23179
R18: 2.7k; R_0603_1608Metric; LCSC C13167
R19, R20, R21, R22, R23, R24, R25, R26: 4.7k; R_0603_1608Metric; LCSC C513565
R27: 10; R_0603_1608Metric; LCSC C144117
R28, R29, R30, R31, R32, R33, R34, R35: 1k; R_0603_1608Metric; LCSC C22548
U0, U1, U2, U3, U4, U5, U6, U7: XTR200; WSON-10-1EP_2x3mm_P0.5mm_EP0.84x2.4mm; LCSC C52091642
U8: SN74LV165; TSSOP-16_4.4x5mm_P0.65mm; LCSC C201716
U9: AT21CS01; SOT-23; LCSC C616192
U10: REF5030EIDR; SOIC-8_3.9x4.9mm_P1.27mm
U11: AD7193; TSSOP-28-1EP_4.4x9.7mm_P0.65mm_EP3.05x7.56mm
U13, U14, U15, U16: OPA2333xxDRB; Texas_S-PVSON-N8; LCSC C2058573
U20: DAC80508ZR; WQFN-16-1EP_3x3mm_P0.5mm_EP1.6x1.6mm; LCSC C2679499
VREF1: TestPoint; TestPoint_Pad_D1.0mm

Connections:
+3.3V: 3V3.1 (1_1), C11.1, C12.1, C13.1, C15.1, C16.1, C17.1, C20.1, C22.1, C24.1, J1.A2 (+3.3V), L1.1, R18.1, U8.16 (VCC), U10.2 (Vin), U11.24 (AVDD), U13.8 (V+), U14.8 (V+), U15.8 (V+), U16.8 (V+), U20.7 (VDD), U20.16 (VIO)
+12V: 12V0.1 (1_1), C1.1, C2.1, C3.1, C4.1, C5.1, C6.1, C7.1, C8.1, C25.1, J1.A30 (+12V), U0.5 (VSP), U1.5 (VSP), U2.5 (VSP), U3.5 (VSP), U4.5 (VSP), U5.5 (VSP), U6.5 (VSP), U7.5 (VSP)
ADC_CS: J1.A5 (ADC_CS), U11.4 (~CS)
AT: J1.A7 (AT), R18.2, U9.1 (SI/O)
CH0: CH0.1 (1_1), J1.A13 (CH0), J1.B13 (CH0), R2.2, U0.6 (OUT)
CH0_B: R2.1, R6.2, U13.3 (+)
CH0_V: C26.1, R28.1, U11.11 (AIN1)
CH1: CH1.1 (1_1), J1.A15 (CH1), J1.B15 (CH1), R10.2, U1.6 (OUT)
CH1_B: R10.1, R14.2, U13.5 (+)
CH1_V: C27.1, R29.1, U11.12 (AIN2)
CH2: CH2.1 (1_1), J1.A18 (CH2), J1.B18 (CH2), R9.2, U2.6 (OUT)
CH2_B: R9.1, R13.2, U14.3 (+)
CH2_V: C28.1, R30.1, U11.13 (AIN3)
CH3: CH3.1 (1_1), J1.A20 (CH3), J1.B20 (CH3), R1.2, U3.6 (OUT)
CH3_B: R1.1, R5.2, U14.5 (+)
CH3_V: C29.1, R31.1, U11.14 (AIN4)
CH4: CH4.1 (1_1), J1.A22 (CH4), J1.B22 (CH4), R4.2, U4.6 (OUT)
CH4_B: R4.1, R8.2, U15.3 (+)
CH4_V: C30.1, R32.1, U11.15 (AIN5)
CH5: CH5.1 (1_1), J1.A24 (CH5), J1.B24 (CH5), R12.2, U5.6 (OUT)
CH5_B: R12.1, R16.2, U15.5 (+)
CH5_V: C31.1, R33.1, U11.16 (AIN6)
CH6: CH6.1 (1_1), J1.A26 (CH6), J1.B26 (CH6), R11.2, U6.6 (OUT)
CH6_B: R11.1, R15.2, U16.3 (+)
CH6_V: C32.1, R34.1, U11.17 (AIN7)
CH7: CH7.1 (1_1), J1.A28 (CH7), J1.B28 (CH7), R3.2, U7.6 (OUT)
CH7_B: R3.1, R7.2, U16.5 (+)
CH7_V: C33.1, R35.1, U11.18 (AIN8)
CP: J1.A8 (A0_MUX), U8.2 (CP)
DAC0: DAC0.1 (1_1), U1.1 (INPUT), U20.2 (OUT0)
DAC1: DAC1.1 (1_1), U0.1 (INPUT), U20.11 (OUT7)
DAC2: DAC2.1 (1_1), U3.1 (INPUT), U20.3 (OUT1)
DAC3: DAC3.1 (1_1), U2.1 (INPUT), U20.10 (OUT6)
DAC4: DAC4.1 (1_1), U5.1 (INPUT), U20.4 (OUT2)
DAC5: DAC5.1 (1_1), U4.1 (INPUT), U20.9 (OUT5)
DAC6: DAC6.1 (1_1), U7.1 (INPUT), U20.5 (OUT3)
DAC7: DAC7.1 (1_1), U6.1 (INPUT), U20.8 (OUT4)
DAC_CS: J1.A6 (DAC_CS), U20.12 (~CS)
DS: J1.A9 (A1_MUX), U8.10 (DS)
GND: C1.2, C2.2, C3.2, C4.2, C5.2, C6.2, C7.2, C8.2, C9.2, C10.2, C11.2, C12.2, C13.2, C14.1, C15.2, C16.2, C17.2, C18.2, C19.2, C20.2, C21.2, C22.2, C23.2, C24.2, C25.2, C26.2, C27.2, C28.2, C29.2, C30.2, C31.2, C32.2, C33.2, D1.1 (K), J1.A3 (GND), J1.A4 (GND), J1.A12 (GND), J1.A14 (CH0), J1.A16 (CH1), J1.A17 (GND), J1.A19 (CH2), J1.A21 (CH3), J1.A23 (CH4), J1.A25 (CH5), J1.A27 (CH6), J1.A29 (CH7), J1.A31 (GND), J1.B2 (GND), J1.B5 (GND), J1.B7 (GND), J1.B10 (GND), J1.B12 (GND), J1.B14 (CH0), J1.B16 (CH1), J1.B19 (CH2), J1.B21 (CH3), J1.B23 (CH4), J1.B25 (CH5), J1.B27 (CH6), J1.B29 (CH7), J1.B32 (GND), R5.1, R6.1, R7.1, R8.1, R13.1, R14.1, R15.1, R16.1, R19.1, R20.1, R21.1, R22.1, R23.1, R24.1, R25.1, R26.1, U0.9 (GND), U0.11 (PAD), U1.9 (GND), U1.11 (PAD), U2.9 (GND), U2.11 (PAD), U3.9 (GND), U3.11 (PAD), U4.9 (GND), U4.11 (PAD), U5.9 (GND), U5.11 (PAD), U6.9 (GND), U6.11 (PAD), U7.9 (GND), U7.11 (PAD), U8.8 (GND), U8.15 (~CE), U9.3 (GND), U10.4 (GND), U11.8 (P0/REFIN-), U11.10 (AINCOM), U11.22 (AGND), U11.23 (DGND), U11.29 (DGND), U13.4 (V-), U13.9 (PAD), U14.4 (V-), U14.9 (PAD), U15.4 (V-), U15.9 (PAD), U16.4 (V-), U16.9 (PAD), U20.6 (GND), U20.17 (Thermal)
MISO_0: J1.B4 (MISO_0), U11.27 (DOUT~RDY)
MISO_1: J1.B9 (MISO_1), U20.15 (SDO/~ALARM)
MOSI_0: J1.B3 (MOSI_0), U11.28 (DIN)
MOSI_1: J1.B8 (MOSI_1), U20.14 (SDI)
unnamed: D1.2 (A), R17.1
unnamed: L1.2, R27.2
unnamed: U0.7 (IS), U0.8 (VG)
unnamed: R22.2, U0.10 (SET)
unnamed: U1.7 (IS), U1.8 (VG)
unnamed: R19.2, U1.10 (SET)
unnamed: U2.7 (IS), U2.8 (VG)
unnamed: R25.2, U2.10 (SET)
unnamed: U3.7 (IS), U3.8 (VG)
unnamed: R20.2, U3.10 (SET)
unnamed: U4.7 (IS), U4.8 (VG)
unnamed: R24.2, U4.10 (SET)
unnamed: U5.7 (IS), U5.8 (VG)
unnamed: R21.2, U5.10 (SET)
unnamed: U6.7 (IS), U6.8 (VG)
unnamed: R26.2, U6.10 (SET)
unnamed: U7.7 (IS), U7.8 (VG)
unnamed: R23.2, U7.10 (SET)
unnamed: C10.1, U10.5 (Trim/NR)
unnamed: R28.2, U13.1, U13.2 (-)
unnamed: R29.2, U13.6 (-), U13.7
unnamed: R30.2, U14.1, U14.2 (-)
unnamed: R31.2, U14.6 (-), U14.7
unnamed: R32.2, U15.1, U15.2 (-)
unnamed: R33.2, U15.6 (-), U15.7
unnamed: R34.2, U16.1, U16.2 (-)
unnamed: R35.2, U16.6 (-), U16.7
PL: J1.A10 (A2_MUX), U8.1 (~PL)
PRSNT: J1.A1 (~PRSNT1), J1.B31 (~PRSNT2)
Q7: J1.A11 (~PERST), U8.9 (Q7)
SCK_0: J1.B1 (SCK_0), U11.3 (SCLK)
SCK_1: J1.B6 (SCK_1), U20.13 (SCLK)
VDDA: C18.1, C23.1, R27.1, U11.25 (DVDD)
VREF: C9.1, C14.2, C19.1, C21.1, U10.6 (Vout), U11.7 (P1/REFIN+), U20.1 (REF), VREF1.1 (1_1)
XTR_EF0: U1.3 (~EF), U8.11 (D0)
XTR_EF1: U3.3 (~EF), U8.12 (D1)
XTR_EF2: U5.3 (~EF), U8.13 (D2)
XTR_EF3: U0.3 (~EF), U8.14 (D3)
XTR_EF4: U7.3 (~EF), U8.4 (D5)
XTR_EF5: U4.3 (~EF), U8.3 (D4)
XTR_EF6: U2.3 (~EF), U8.5 (D6)
XTR_EF7: U6.3 (~EF), U8.6 (D7)
XTR_OD: J1.B11 (~PERST), R17.2, U0.4 (OD), U1.4 (OD), U2.4 (OD), U3.4 (OD), U4.4 (OD), U5.4 (OD), U6.4 (OD), U7.4 (OD)

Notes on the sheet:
Voltage Sense Divider
ADC
XTR200
Use X7R for C17, C18
; ============================================================================ ; padne directives - KOI 8x8 daughterboard ; rev: A30=+12V, C25 bulk, U9 AT21CS01, R18=2.7k ; 2026-07-30: C23 moved +3.3V -> VDDA (now 1.1uF on the filtered node); ; R27 1.5 -> 10 ohm; L1 DCR 0.1 -> 0.38 (Sunlord GZ1608U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
Best to use REF5030EIDR
https://tinyurl.com/2yfhrjrp
Use capacitors above 16V CC0603KRX7R9BB104 - C14663 100nF 50V X7R ±10% 0603 Multilayer Ceramic Capacitors MLCC - SMD/SMT ROHS YAGEO RT0603BRD074K7L 4.7k -55℃~+155℃ 100mW 4.7kΩ 75V
Buffers
EEPROM 1KB
XTR200 Error Flag
DAC
Architecture
Custom PCIe x4
Precision Reference
Finish the pico driver Internal reference span error: 0.2% Figure out DAC power up sequence
12V
DAC80508Z
2.5V
AD7193
Make sure to buy 0.1% tolarence with 10ppm resistors for best performance 27k: ERA-2VRB2702X 100k YAGEO RT0603BRD07100KL: -55℃~+155℃ 100kΩ 100mW 75V Thin Film Resistor ±0.1% ±25ppm/℃ 0603 Chip Resistor - Surface Mount ROHS 20k Vishay MCT06030D2002BP500: -55℃~+125℃ 100mW 20kΩ 75V Thin Film Resistor 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
3.3V
PCIe-x4 PIN 12-32
PCIe-x4 PIN 1-11

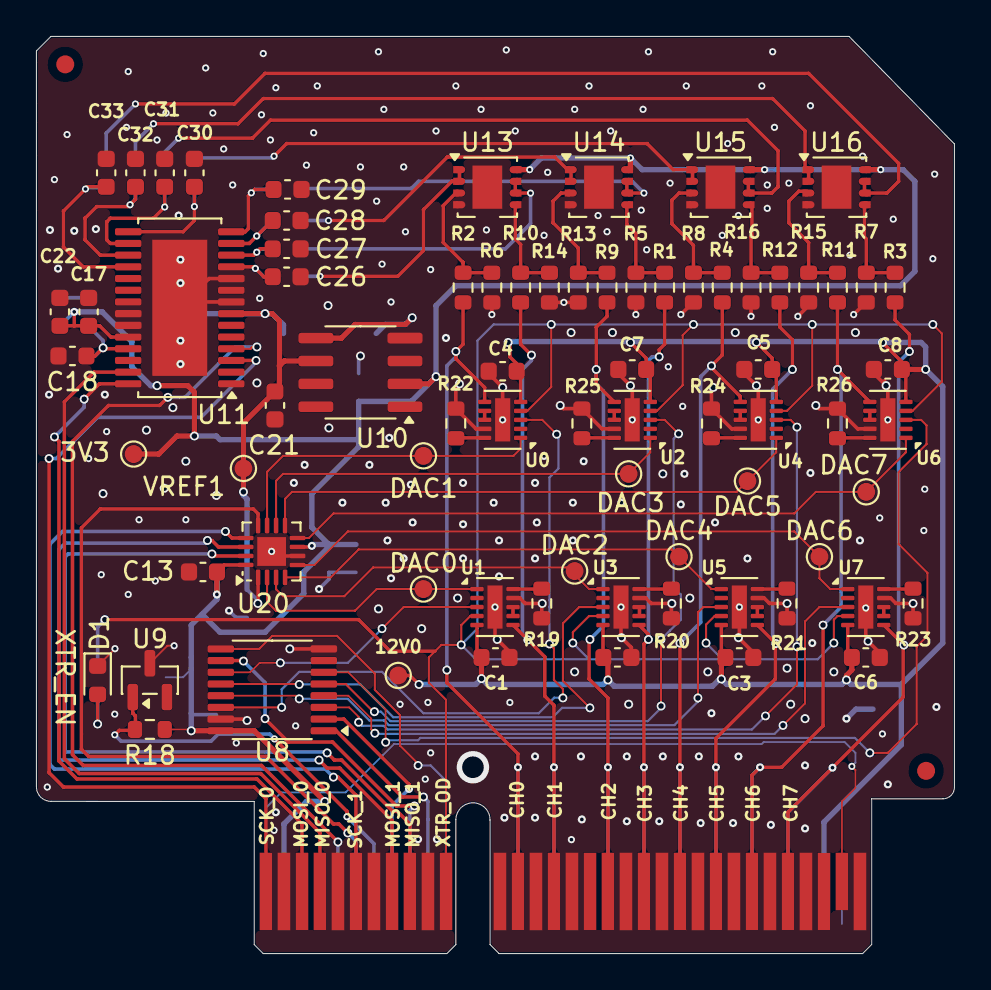
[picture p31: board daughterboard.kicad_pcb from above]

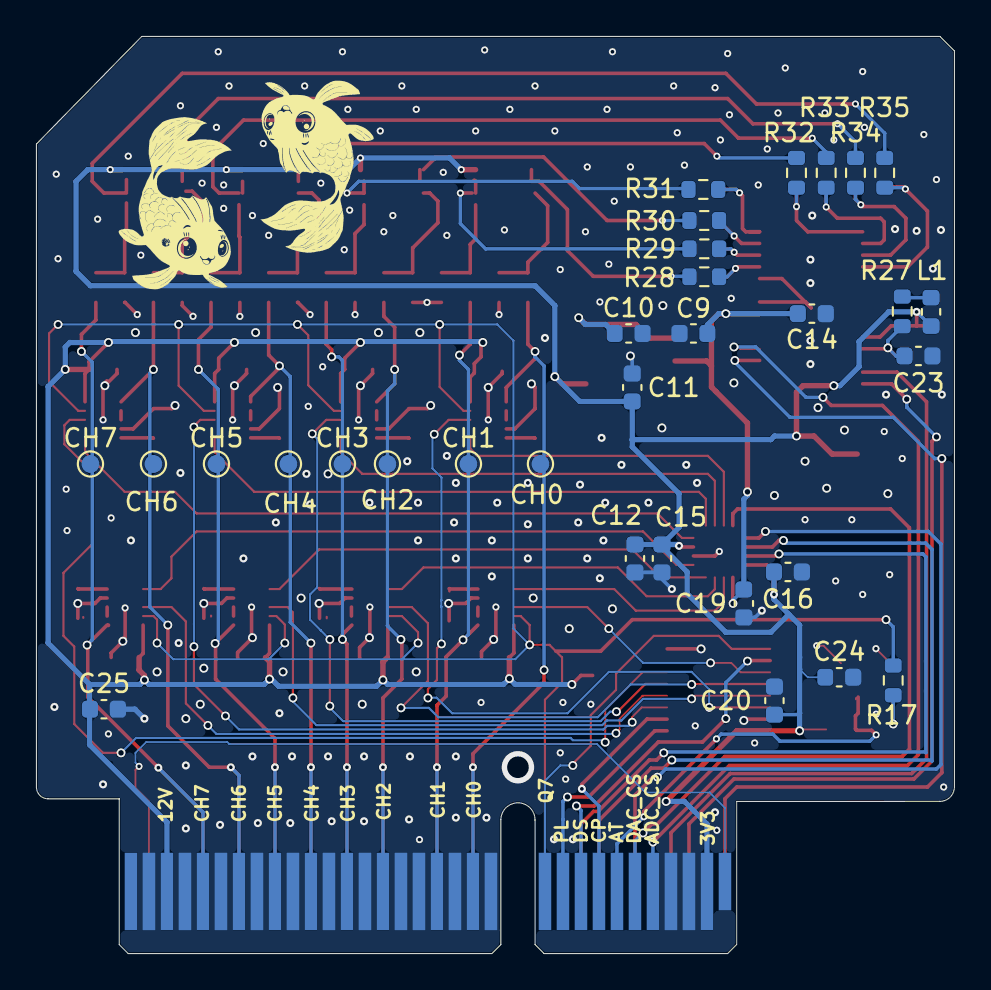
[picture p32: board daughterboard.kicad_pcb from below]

Board: 4 copper layers, 51.0 x 51.0 mm, 109 parts (31 on the bottom side), 87 nets.

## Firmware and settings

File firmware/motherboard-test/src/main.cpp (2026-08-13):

/*
 * main.cpp — Host-commanded 8×8 current driver (DAC80508 → XTR200 → AD7193)
 *
 * One Pico controls up to 8 daughterboards × 8 channels = 64 current-source
 * channels. The host PC speaks a line-based ASCII protocol over USB serial:
 * it loads per-channel current setpoints (mA), then reads back the voltage each
 * channel develops across its load (a TiN heater on the photonic chip). The
 * host derives resistance / power; the firmware only sources current + reports
 * voltage.
 *
 * Channel addressing is a flat global index g = board*8 + channel, 0..63.
 *
 * Chip-select for both banks comes from two 74HC138 decoders sharing the
 * address lines A0=GP20, A1=GP21, A2=GP22 with their own active-low enables:
 *   ADC_EN=GP5, DAC_EN=GP6. Decoder outputs are inverted (Y0=CS8 ... Y7=CS1),
 *   handled inside HC138::selectDevice().
 *
 * ADC bus (SPI0): GP2=SCK, GP3=MOSI, GP4=MISO   (shared with SN74LV595)
 * DAC bus (SPI1): GP10=SCK, GP11=SDI            (write-only, no MISO/SDO)
 * SN74LV595 XTR_OD front-end enables: shares SPI0, RCLK=GP7
 * SN74LV165 XTR200 ERRORFLAG readback: one per daughterboard, daisy-chained
 *   board1→…→board8, bit-banged on dedicated pins (NOT on SPI0):
 *   CP=GP16 (shift clock), Q7 of board 8 = GP17 (serial data), PL=GP18 (load)
 *
 * ──────────────────────────────────────────────────────────────────────────
 * HOST COMMAND PROTOCOL  (commands and replies are '\n'-terminated; every
 * command produces exactly one reply line so the host stays in sync)
 *
 * Two-way ack: every "OK" reply ECHOES its command name, so the host can
 * verify a reply belongs to the command it just sent and resync/retry if not.
 * Any line the firmware emits on its own (boot banner, cal progress, STREAM)
 * starts with '#' — an unprefixed line is always a direct command reply.
 *
 *   *IDN?               -> KOI,8x8,fw1.3
 *   *RST                -> OK *RST   (all currents 0, all front-ends disabled)
 *   ISETA i0 i1 .. i63  -> OK ISETA  (set all 64 currents in mA, g-order)
 *   ISET g mA           -> OK ISET <g>  (set one channel)
 *   MEASA?              -> v0,..,v63 (measure all 64; "nan" for unpopulated)
 *   MEASA? <mask>       -> v0,..,v63 (only boards whose bit is set in mask)
 *   MEAS? g             -> <volts>   (measure one channel; "nan" if absent)
 *   XTR <enmask>        -> OK XTR 0x..  (bit b = 1 enables board b's front-ends)
 *   AVG n               -> OK AVG <n>  (1..64 on-micro averages per measurement)
 *   RATE fs             -> OK RATE <fs>  (AD7193 filter word 1..1023; sets both
 *                          the scan and single-conversion filter rate)
 *   GAIN g              -> OK GAIN <g>  (AD7193 PGA gain 1|8|16|32|64|128;
 *                          folded into the reported voltage, triggers a recal)
 *   CHOP ON|OFF         -> OK CHOP ..  (chopper offset/drift cancellation; recal)
 *   FILTER SINC3|SINC4  -> OK FILTER .. (digital filter type: SINC3 faster settle,
 *                          SINC4 better rejection/noise — the default)
 *   REJ60 ON|OFF        -> OK REJ60 .. (simultaneous 50/60 Hz notch rejection)
 *   BIPOLAR ON|OFF      -> OK BIPOLAR .. (input polarity: OFF=unipolar 0..FS, the
 *                          default; ON=bipolar ±FS so small negatives don't clamp)
 *   BUF ON|OFF [CAL]    -> OK BUF ..    (AD7193 input buffer, fw1.3. ON is the
 *                          only setting valid for normal use — the 6:1 divider
 *                          is a ~16.7 kΩ source. OFF needs an SMU driving the
 *                          pin directly and is for the measure-path A/B in
 *                          docs/measure-path-offset.md §5. NO recal by default:
 *                          whenever BUF OFF is legitimately in use the input is
 *                          being forced to a non-zero voltage, which a
 *                          zero-scale cal would silently absorb. Add CAL, with
 *                          the input at 0 V, to refresh the offset.)
 *   ADC?                -> OK ADC rate=.. avg=.. gain=.. chop=.. filter=.. rej60=..
 *                          polarity=uni|bi buf=0|1  (live sampling settings)
 *   STREAM ON|OFF       -> OK STREAM  (periodic '# v0,..' dump for eyeballing)
 *   RESCAN              -> OK RESCAN active=0x.. new=0x..  (re-detect boards)
 *   PING? b             -> OK PING <b> 1|0  (board liveness: ID + one real ADC
 *                          conversion, non-mutating; 0 for an undetected board
 *                          — use RESCAN to adopt it. The ADC is the only
 *                          readback on a board, so a passing PING is the proxy
 *                          that the whole board (incl. the write-only DAC's
 *                          shared select path) is seated and powered.)
 *   DACINIT [b]         -> OK DACINIT 0x<mask>  (rewrite DAC config: soft
 *                          reset, external ref, REFDIV÷2 gain, reload
 *                          setpoints — board b or all populated. Recovery for
 *                          a DAC that browned out back to its internal 2.5 V
 *                          reference; mask = boards actually reinitialized.)
 *   CAL [b]             -> OK CAL 0x<mask>  (run AD7193 internal zero/full-scale
 *                          cal with the XTR200 front-ends forced off, board b or
 *                          all populated; mask = boards calibrated)
 *   CALCLR [b]          -> OK CALCLR 0x<mask>  (clear user cal: reset ADC to
 *                          factory offset/full-scale + rewrite config, board b or
 *                          all populated — A/B against CAL for the offset)
 *   ERR?                -> OK ERR 0x<16 hex>  (snapshot of all 64 XTR200
 *                          ERRORFLAG pins via the SN74LV165 chain; bit g =
 *                          RAW level at channel g's EF pin — the host applies
 *                          polarity. Bits of unpopulated boards are garbage:
 *                          a missing board breaks the chain, mask by the
 *                          active-board set.)
 *
 * Reported voltage is the RAW ADC-pin voltage (computed in double for full
 * 24-bit resolution). The host applies the known 6:1 input divider to recover
 * the true heater voltage (heater_V = reported_V × 6).
 * Errors reply "ERR <reason>".
 * ──────────────────────────────────────────────────────────────────────────
 */

#include <Arduino.h>
#include <SPI.h>
#include <string.h>
#include <strings.h>
#include <stdlib.h>
#include "HC138.h"
#include "DAC80508.h"
#include "AD7193.h"
#include "XTR595.h"

// ── Shared 74HC138 chip-select ──────────────────────────
#define PIN_ADDR0     20
#define PIN_ADDR1     21
#define PIN_ADDR2     22
#define PIN_ADC_EN     5
#define PIN_DAC_EN     6
#define PIN_XTR_RCLK   7

// ── SN74LV165 XTR200 ERRORFLAG chain (bit-banged, dedicated pins) ──
#define PIN_ERR_CP    16   // shift clock (rising edge)
#define PIN_ERR_Q7    17   // serial data: Q7 of the LAST 165 in the chain (board 8)
#define PIN_ERR_PL    18   // parallel load, active low (CLK INH tied low on-board)

// ── System size ─────────────────────────────────────────
#define NUM_BOARDS     8
#define CH_PER_BOARD   8
#define TOTAL_CH       (NUM_BOARDS * CH_PER_BOARD)   // 64

// ── References ──────────────────────────────────────────
#define VREF       3.0f
#define ADC_VREF   3.0f

// NOTE: there is a 6:1 resistor divider (100k/20k) in front of each AD7193
// input. The firmware reports the RAW ADC-pin voltage; the host multiplies by
// 6 to get the heater voltage (e.g. 2.5 V heater → 416.7 mV at the ADC pin).

// Current → DAC-voltage calibration. Ideal XTR200 transconductance gives
// I[mA] = 10 · Vdac / 4.7kΩ  →  Vdac = 0.47 · I[mA]. Per-channel slope/offset
// are placeholders here; overwrite with Keithley-fit constants later.
#define CAL_SLOPE_DEFAULT   0.47f   // volts per mA
#define CAL_OFFSET_DEFAULT  0.00f   // volts

// ── Buses + decoders ────────────────────────────────────
HC138 adcSelect(PIN_ADDR0, PIN_ADDR1, PIN_ADDR2, PIN_ADC_EN);
HC138 dacSelect(PIN_ADDR0, PIN_ADDR1, PIN_ADDR2, PIN_DAC_EN);

//                            MISO  MOSI  SCK
// Must match the wiring: the AD7193 DOUT lines land on GP4, so the ADC read
// path is SPI0. Moving adcSpi to SPI1 (GP12 MISO, an unconnected pin) makes
// every device read back 0x00 — ID mismatch on all 8, boards present or not.
arduino::MbedSPI dacSpi(       12,   11,   10);   // DAC on SPI1, write-only (MISO unused)
arduino::MbedSPI adcSpi(        4,    3,    2);   // ADC + 595 share SPI0

DAC80508     dac(&dacSelect, &dacSpi, NUM_BOARDS, VREF);
AD7193Driver adc(&adcSelect, &adcSpi, NUM_BOARDS);
XTR595       xtr(&adcSpi, PIN_XTR_RCLK);

// ── Runtime state ───────────────────────────────────────
bool     boardActive[NUM_BOARDS];
float    setpoint_mA[TOTAL_CH];
float    calSlope[TOTAL_CH];
float    calOffset[TOTAL_CH];
uint8_t  avgCount = 4;            // on-micro averages per measurement (default 4)
uint16_t adcRate  = 16;          // AD7193 filter word (FS) used for fast scans.
                                 //   Default 16 (~0.9 s full-grid refresh, quieter
                                 //   than FS=8). Per-channel time ≈ 0.83 ms × FS
                                 //   (SINC4 settling, ~4 conv periods — NOT 1/ODR):
                                 //   FS=8 ≈ 8 ms/ch, FS=240 ≈ 0.2 s/ch. Higher
                                 //   FS = slower/cleaner. ODR = 4.92MHz/(1024·FS).
// AD7193 sampling settings (host-tunable; applied to every populated board by
// writeBoardConfig, so they survive RESCAN/reset). CHOP + REJ60 + SINC3 trade
// speed for noise/offset; gain is the PGA field (folded into codeToVolts so the
// reported voltage stays the true ADC-pin voltage regardless of gain).
uint8_t  adcGain  = AD7193_CONF_GAIN_1;  // encoded CONF gain field (not the ×N)
bool     adcChop  = false;       // CHOP: chopper offset/drift cancellation
bool     adcSinc3 = false;       // filter: false = SINC4 (default), true = SINC3
bool     adcRej60 = false;       // simultaneous 50/60 Hz notch rejection
bool     adcBipolar = false;     // false = unipolar (0..FS), true = bipolar (±FS)
// AD7193 input buffer. ON is the only setting valid for normal use here: the
// 6:1 sense divider presents ~16.7 kΩ, and unbuffered mode needs a low-impedance
// source driving the pin directly (an SMU on a desoldered channel). OFF exists
// for the measure-path A/B in docs/measure-path-offset.md §5 — with BUF on, the
// absolute input range is AGND+250 mV..AVDD−250 mV and that applies to AINCOM,
// which is tied to AGND here, so the part is out of spec by construction.
bool     adcBuf = true;
uint8_t  xtrState = 0xFF;        // OD bits: 1 = disabled, 0 = enabled

bool     streamOn = false;
uint32_t streamInterval = 1000;
uint32_t streamLast = 0;

// ── Line buffer ─────────────────────────────────────────
#define LINE_MAX 768             // enough for "ISETA " + 64 floats
static char     lineBuf[LINE_MAX];
static uint16_t lineLen = 0;

// Assembled MEASA/STREAM reply (64 values × up to ~14 chars). Built fully in
// RAM, then emitted in a single write so the host sees one atomic line.
static char     measBuf[1024];

// ════════════════════════════════════════════════════════
// Helpers
// ════════════════════════════════════════════════════════
static uint16_t mAToCode(uint8_t g, float mA) {
    float v = calSlope[g] * mA + calOffset[g];
    if (v < 0.0f) v = 0.0f;
    if (v > VREF) v = VREF;
    return DAC80508::voltageToCode(v, VREF);
}

// Per-board DAC-output scramble.
// The AD7193 inputs are wired sequentially (ADC input n senses physical channel
// n), so the read path is identity. The DAC80508 outputs, however, are permuted
// on the daughterboard: out0→ch1, out1→ch3, out2→ch5, out3→ch7, out4→ch6,
// out5→ch4, out6→ch2, out7→ch0. To source current into physical channel p we
// drive the DAC output that lands on p — the inverse map below. (All
// daughterboards share the layout, so one table serves all.)
static const uint8_t DAC_CH_FOR_PHYS[CH_PER_BOARD] = {7, 0, 6, 1, 5, 2, 4, 3};

// Forward map (inverse of DAC_CH_FOR_PHYS): DAC-output index → physical channel,
// i.e. out0→ch1, out1→ch3, … out7→ch0. The XTR200 front ends — and their
// ERRORFLAG pins on the SN74LV165 chain — are laid out in this same DAC-output
// order, so readErrorChain() uses it to place each flag on its physical channel.
static const uint8_t PHYS_FOR_DAC[CH_PER_BOARD] = {1, 3, 5, 7, 6, 4, 2, 0};

static void writeChannel(uint8_t g) {
    uint8_t b  = g / CH_PER_BOARD;
    uint8_t ch = g % CH_PER_BOARD;             // physical channel
    if (!boardActive[b]) return;
    dac.setDAC(b, DAC_CH_FOR_PHYS[ch], mAToCode(g, setpoint_mA[g]));
}

// Decode the CONF gain field into its numeric PGA gain (×1..×128).
static inline uint16_t adcGainValue() {
    switch (adcGain) {
        case AD7193_CONF_GAIN_8:   return 8;
        case AD7193_CONF_GAIN_16:  return 16;
        case AD7193_CONF_GAIN_32:  return 32;
        case AD7193_CONF_GAIN_64:  return 64;
        case AD7193_CONF_GAIN_128: return 128;
        default:                   return 1;   // AD7193_CONF_GAIN_1
    }
}

// Non-channel MODE flags common to every mode write (idle/single/scan): internal
// clock (mandatory — no crystal) plus the host-tunable SINC3 / REJ60 filter bits.
static inline uint32_t adcModeFlags() {
    uint32_t m = AD7193_MODE_CLKSRC_INT;
    if (adcSinc3) m |= AD7193_MODE_SINC3;
    if (adcRej60) m |= AD7193_MODE_REJ60;
    return m;
}

static inline double codeToVolts(uint32_t raw) {
    // V_in referred to the ADC pin (÷gain so the host's 6:1 divider stays gain-
    // independent). Double keeps full 24-bit precision. Unipolar: 0..FS maps
    // 0..2^24. Bipolar: ±FS maps 0..2^24 with midscale (2^23) = 0 V, so small
    // negative offsets read as negative instead of clamping at 0.
    double g = (double)adcGainValue();
    if (adcBipolar)
        return (((double)raw / 8388608.0) - 1.0) * (double)ADC_VREF / g;
    return ((double)raw / 16777216.0) * (double)ADC_VREF / g;
}

// Measure one channel: average avgCount single conversions and return the RAW
// ADC-pin voltage. Done in double because a 24-bit code exceeds a 32-bit
// float's mantissa — float would silently drop the bottom bits. The host
// applies the 6:1 divider to recover the heater voltage.
static double measureChannel(uint8_t g) {
    uint8_t b  = g / CH_PER_BOARD;
    uint8_t ch = g % CH_PER_BOARD;             // physical channel == ADC input
    uint8_t n  = avgCount < 1 ? 1 : avgCount;
    uint64_t acc = 0;
    for (uint8_t i = 0; i < n; i++) {
        acc += adc.singleConversion(b, AD7193_CONF_CHAN(ch));
    }
    return codeToVolts((uint32_t)(acc / n));
}

// Measure all 64 channels into `out` as a CSV line, THEN return — nothing is
// printed during the (slow) measurement, so the caller emits the whole reply in
// one burst. Each populated board is read with ONE continuous-sequencer pass
// (all 8 channels), which avoids the per-channel single-conversion restart
// overhead. `bmask` bit b gates board b; avgCount passes are averaged.
static void buildMeasureLine(char* out, size_t cap, uint8_t bmask) {
    double vals[TOTAL_CH];
    bool   ok[TOTAL_CH];
    for (uint16_t g = 0; g < TOTAL_CH; g++) ok[g] = false;

    uint8_t n = avgCount < 1 ? 1 : avgCount;
    for (uint8_t b = 0; b < NUM_BOARDS; b++) {
        if (!boardActive[b] || !(bmask & (1 << b))) continue;

        uint64_t acc[CH_PER_BOARD]  = {0};
        uint8_t  good[CH_PER_BOARD] = {0};
        for (uint8_t a = 0; a < n; a++) {
            uint32_t codes[CH_PER_BOARD] = {0};
            uint8_t got = adc.scanContinuous(b, adc.confReg[b], adcRate,
                                             CH_PER_BOARD, codes, adcModeFlags());
            for (uint8_t ch = 0; ch < CH_PER_BOARD; ch++) {
                if (got & (1u << ch)) { acc[ch] += codes[ch]; good[ch]++; }
            }
        }
        for (uint8_t ch = 0; ch < CH_PER_BOARD; ch++) {
            // ADC input == physical channel == g-channel (sequential wiring).
            uint16_t g = b * CH_PER_BOARD + ch;
            if (good[ch]) { vals[g] = codeToVolts(acc[ch] / good[ch]); ok[g] = true; }
        }
    }

    size_t p = 0;
    for (uint16_t g = 0; g < TOTAL_CH; g++) {
        if (g && p < cap - 1) out[p++] = ',';
        if (ok[g]) {
            String num(vals[g], 6);                  // double → string, 6 dp
            const char* s = num.c_str();
            while (*s && p < cap - 1) out[p++] = *s++;
        } else {
            const char* s = "nan";
            while (*s && p < cap - 1) out[p++] = *s++;
        }
    }
    out[p] = '\0';
}

// Write the ADC config + mode registers (no internal calibration). Splitting
// this out lets detection configure a board cheaply before confirming it with a
// conversion — without paying the (5 s-timeout-per-call) internal cal on a board
// that may be absent. The internal clock select is mandatory: with the default
// (external-crystal) clock bits and no crystal, RDY never asserts.
static void writeBoardConfig(uint8_t b) {
    // Pseudo-differential, REFIN2, channel AIN1; gain, CHOP, polarity
    // (uni/bipolar) and the input buffer from the host-tunable settings.
    adc.confReg[b] = AD7193_CONF_PSEUDO | AD7193_CONF_REFSEL | AD7193_CONF_REFDET |
                     (adcGain & AD7193_CONF_GAIN_MASK) | AD7193_CONF_CHAN(0);
    if (adcBuf)      adc.confReg[b] |= AD7193_CONF_BUF;
    if (!adcBipolar) adc.confReg[b] |= AD7193_CONF_UNIPOLAR;
    if (adcChop)     adc.confReg[b] |= AD7193_CONF_CHOP;
    adc.writeRegister(b, AD7193_REG_CONF, adc.confReg[b]);

    // Idle, internal clock + filter flags, filter word = adcRate. Using adcRate
    // (not a fixed 96) keeps MEAS?'s singleConversion in sync with MEASA?'s scan.
    adc.modeReg[b] = AD7193_MODE_IDLE | adcModeFlags() | AD7193_MODE_RATE(adcRate);
    adc.writeRegister(b, AD7193_REG_MODE, adc.modeReg[b]);
}

static void configureBoard(uint8_t b) {
    writeBoardConfig(b);
    // Force ALL XTR200 front-ends OFF across the AD7193 internal zero/full-scale
    // calibration, then restore. An enabled front-end sources its offset current
    // into the load during the cal, which biases the zero-scale point — that
    // stray offset is exactly what we were chasing. At boot xtrState is already
    // 0xFF (disabled); on a runtime RESCAN it holds the live enables, so saving
    // and restoring it leaves the enable state untouched.
    uint8_t savedXtr = xtrState;
    xtr.setOutputs(0xFF);                 // OD all high = all front-ends disabled
    adc.calibrateInternalZero(b);
    adc.calibrateInternalFull(b);
    xtr.setOutputs(savedXtr);             // restore prior enable state
}

// Re-apply the current ADC sampling settings to every populated board after a
// live setting change. `recal` runs the full internal zero/full-scale cal
// (configureBoard) — needed when CHOP changes; rate/filter changes just
// rewrite CONF+MODE (writeBoardConfig), no recal required.
static void reapplyAdcSettings(bool recal) {
    for (uint8_t b = 0; b < NUM_BOARDS; b++) {
        if (!boardActive[b]) continue;
        if (recal) configureBoard(b);
        else       writeBoardConfig(b);
    }
}

// Re-apply settings + run a ZERO-SCALE-ONLY cal on every populated board — used
// on a gain change. The AD7193's offset register is gain-dependent: a stale
// gain-1 offset applied at a higher gain over-subtracts and clamps the unipolar
// result to 0. Internal zero-scale cal is valid at any gain, so re-run it at the
// new gain; the full-scale coefficient (valid only at gain 1) is left untouched
// from boot — running full-scale cal here would corrupt it. Front-ends forced
// off across the cal so no XTR200 offset current biases the zero point.
static void recalZeroScaleActive() {
    uint8_t savedXtr = xtrState;
    xtr.setOutputs(0xFF);                 // OD all high = all front-ends disabled
    for (uint8_t b = 0; b < NUM_BOARDS; b++) {
        if (!boardActive[b]) continue;
        writeBoardConfig(b);              // apply the new gain first
        adc.calibrateInternalZero(b);     // offset cal at the new gain
    }
    xtr.setOutputs(savedXtr);             // restore prior enable state
}

// ── Board presence detection ────────────────────────────
// The DAC has no readback, so the AD7193 is our only "is this board here?"
// signal — and a bare ID-nibble read is not enough: an absent board floats the
// shared MISO and can read a stray 0x02, while a present board with a flaky
// (HASL) contact can read garbage or be left SPI-desynced. So presence is
// confirmed by ACTUALLY READING THE ADC: the board must both report the ID
// nibble AND complete a real conversion (probeConversion → RDY toggles instead
// of timing out). Taking a moment per board is fine and intended.
#define DETECT_ATTEMPTS   4      // resync+confirm tries before giving up
#define DETECT_RETRY_MS   40     // settle between tries (rides out a contact glitch)
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
void loop() {
    // Drain any pending command bytes (non-blocking, one line at a time).
    while (Serial.available()) {
        char c = (char)Serial.read();
        if (c == '\n' || c == '\r') {
            if (lineLen > 0) {
                lineBuf[lineLen] = '\0';
                processLine(lineBuf);
                lineLen = 0;
            }
        } else if (lineLen < LINE_MAX - 1) {
            lineBuf[lineLen++] = c;
        } else {
            lineLen = 0;
            replyErr("line too long");
        }
    }

    // Optional eyeball stream (debug only; prefixed '#' so the host can ignore).
    if (streamOn && (millis() - streamLast >= streamInterval)) {
        streamLast = millis();
        buildMeasureLine(measBuf, sizeof(measBuf), 0xFF);
        Serial.print("# ");
        Serial.println(measBuf);
    }
}

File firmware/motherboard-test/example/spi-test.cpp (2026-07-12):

/**
 * AD7193 Dual-Chip Driver Test Program
 *
 * Tests two AD7193 24-bit sigma-delta ADCs on Raspberry Pi Pico.
 * Both chips share the same SPI bus, each with its own CS pin.
 *
 * Wiring (Pico -> AD7193 #1 & #2):
 *   GP17 -> CS1   (AD7193 #1 - Pin 9 /CS)
 *   GP20 -> CS2   (AD7193 #2 - Pin 9 /CS)
 *   GP18 -> SCLK  (Both chips - Pin 2 SCLK, wired in parallel)
 *   GP19 -> MOSI  (Both chips - Pin 10 DIN, wired in parallel)
 *   GP16 -> MISO  (Both chips - Pin 13 DOUT/RDY, wired in parallel)
 *
 *   Both AD7193 chips:
 *   AVDD, DVDD -> 3.3V
 *   AGND, DGND -> GND
 *   AINCOM     -> GND
 *   REFIN1(+)  -> 2.5V reference
 *   REFIN1(-)  -> GND
 */

extern "C" {
#include "ad7193.h"
}

#include "pico/stdlib.h"
#include <stdio.h>

// ============================================================================
// Pin Definitions — adjust to match your wiring
// ============================================================================
#define PIN_CS1   17   // Chip Select for ADC #1
#define PIN_CS2   20   // Chip Select for ADC #2
#define PIN_SCK   18
#define PIN_MOSI  19
#define PIN_MISO  16

// Reference voltage (adjust to your setup)
#define VREF      2.5f

// ============================================================================
// Helper: gain enum to numeric value
// ============================================================================
static uint8_t gain_to_value(uint8_t gain_bits) {
    switch (gain_bits) {
        case AD7193_CONF_GAIN_1:   return 1;
        case AD7193_CONF_GAIN_8:   return 8;
        case AD7193_CONF_GAIN_16:  return 16;
        case AD7193_CONF_GAIN_32:  return 32;
        case AD7193_CONF_GAIN_64:  return 64;
        case AD7193_CONF_GAIN_128: return 128;
        default:                   return 1;
    }
}

// ============================================================================
// Test 1: Device Identification
// ============================================================================
static bool test_device_id(ad7193_dev_t *dev) {
    printf("\n--- Test 1: Device ID ---\n");

    uint8_t id = ad7193_get_id(dev);
    printf("  ID Register: 0x%02X\n", id);
    printf("  Device Family (lower nibble): 0x%X\n", id & 0x0F);
    printf("  Silicon Revision (upper nibble): 0x%X\n", (id >> 4) & 0x0F);

    bool pass = ((id & AD7193_ID_MASK) == AD7193_ID_VALUE);
    printf("  Result: %s\n", pass ? "PASS" : "FAIL");
    return pass;
}

// ============================================================================
// Test 2: Register Read/Write
// ============================================================================
static bool test_register_rw(ad7193_dev_t *dev) {
    printf("\n--- Test 2: Register Read/Write ---\n");

    // Read the current mode register
    uint32_t mode_orig = ad7193_read_reg(dev, AD7193_REG_MODE);
    printf("  Mode Register (original): 0x%06lX\n", mode_orig);

    // Write a known value (change the rate to 200, different from default 96)
    uint32_t mode_test = (mode_orig & ~0x3FF) | 200;
    ad7193_write_reg(dev, AD7193_REG_MODE, mode_test);

    // Read it back
    uint32_t mode_read = ad7193_read_reg(dev, AD7193_REG_MODE);
    printf("  Mode Register (written):  0x%06lX\n", mode_test);
    printf("  Mode Register (readback): 0x%06lX\n", mode_read);

    bool pass = (mode_read == mode_test);
    printf("  Result: %s\n", pass ? "PASS" : "FAIL");

    // Restore original
    ad7193_write_reg(dev, AD7193_REG_MODE, mode_orig);
    dev->mode_reg = mode_orig;

    return pass;
}

// ============================================================================
// Test 3: Register Dump
// ============================================================================
static void test_register_dump(ad7193_dev_t *dev) {
    printf("\n--- Test 3: Full Register Dump ---\n");
    ad7193_dump_registers(dev);
}

// ============================================================================
// Test 4: Internal Calibration
// ============================================================================
static void test_calibration(ad7193_dev_t *dev) {
    printf("\n--- Test 4: Internal Calibration ---\n");
    ad7193_calibrate_internal_zero(dev);
    ad7193_calibrate_internal_full(dev);
}

// ============================================================================
// Test 4b: Internal Short Self-Test
// ============================================================================
static void test_internal_short(ad7193_dev_t *dev) {
    printf("\n--- Test 4b: Internal Short Self-Test (AIN2-AIN2) ---\n");
    printf("  This shorts AIN2 to itself internally.\n");
    printf("  Expected result: ~0V (should be very close to zero)\n\n");

    // Use bipolar mode for this test so we can see if it's near zero
    ad7193_set_pseudo_diff(dev, false);
    ad7193_set_unipolar(dev, false);  // Bipolar: midscale = 0V
    ad7193_set_buffer(dev, true);
    ad7193_set_gain(dev, AD7193_CONF_GAIN_1);
    ad7193_set_rate(dev, 96);

    // Read the short channel (CH9 = bit 17 = AIN2-AIN2)
    uint32_t raw = ad7193_single_conversion(dev, AD7193_CH_SHORT);
    float voltage = ad7193_code_to_voltage(raw, VREF, 1, false);
    printf("  SHORT channel: Raw=0x%06lX  Voltage=%.6f V\n",
           (unsigned long)raw, voltage);

    if (raw == 0xFFFFFF || raw == 0x000000) {
        printf("  WARNING: Saturated reading! SPI may not be working correctly.\n");
    } else if (raw >= 0x7F0000 && raw <= 0x810000) {
        printf("  PASS: Reading is near midscale (0V in bipolar). ADC is working!\n");
    } else {
        printf("  NOTE: Reading is offset from zero. May need calibration.\n");
    }
}
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

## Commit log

2026-07-25 add board
    [daughterboard.kicad_pcb, daughterboard.kicad_sch]
2026-07-27 updated daughterboard with eeprom and some layout improvements and padne simulations
    [bom.csv, daughterboard.kicad_pcb, master_bom.csv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]
2026-07-27 Update root CLAUDE.md for daughterboard rev + PDN simulation workflow
    Documents the new EEPROM/layout-improvement revision, the archived
    version 1/ folder, and the padne PDN simulation → ParaView export →
    results plot pipeline.
2026-07-27 Add detailed CLAUDE.md for hardware/daughterboard/
    Documents the current-vs-version-1 revision split, the netlist/fab
    files, the orphaned x1/x2/x3 schematic copies, and the padne PDN
    simulation pipeline (.padne project -> padne_out*/.vtu ParaView
    export -> padne_plots_v2.py -> results*/ plots), including why v2 of
    the plotting script differs from v1. Root CLAUDE.md now points here
    instead of duplicating the PDN details.
2026-07-27 Add per-board README with images for daughterboard and motherboard
    Human-facing overview of each board (renders, key parts table, file
    guide) mirroring the top-level README's style, scoped to each
    hardware/ subdirectory.
2026-07-27 Update status: all 8 daughterboards populated and tested
    Open item: a ~3 mV offset found during the 8-board test needs
    root-causing before it's fully closed out.
2026-07-30 Rework AD7193 DVDD pi filter; resolve L1/R27 BOM TBDs
    The DVDD filter (C17 - L1/R27 - C18) had all its local capacitance on the
    unfiltered side: C22+C23+C17 = 1.2 uF on +3.3V, versus 100 nF on VDDA.
    - Move C23 (1 uF) from +3.3V to VDDA. Zero BOM/placement change: it was
    already back-to-back with C18 at (87.50, 84.00). Filtered node goes
    100 nF -> 1.1 uF. Removed the stale +3.3V routing that ran through the
    pad, which would otherwise have shorted out L1 and R27.
    - R27 1.5 -> 10 ohm. Corner 97 kHz -> 14 kHz for 4.2 mV drop; AD7193 DIDD
    is 0.4 mA (internal oscillator, no crystal fitted). Damping Q = 0.09.
    - L1 resolved to C96708 (Sunlord GZ1608U601CTF, 600R@100MHz, 380 mohm,
    500 mA).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
    [bom.csv, daughterboard.kicad_pcb, daughterboard.kicad_sch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]
2026-08-05 Respace PCIe connectors to even 18mm pitch and reroute
    Place J1-J8 on an exact 18.0mm pitch centred on the board (X 82.5-232.5,
    centre 157.5), replacing the previous irregular 17.0-19.0mm spacing.
    Each connector moves <=1.5mm; outermost copper lands at X 88.85/226.35,
    clear of the board outline.
    The move severed every connector-side connection (195 track endpoints sat
    on old pad positions, 0 on new ones), so the affected nets were ripped and
    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
    [motherboard.kicad_pcb]
2026-08-05 update pcb
    [motherboard.kicad_pcb, motherboard.kicad_sch, motherboard_bak.kicad_pcb]
2026-08-08 Motherboard: protected power input, K7805 switcher, working 3V3_EN interlock
    Rework the motherboard power tree from the barrel jack to the 3.3 V rail.
    Design rationale and verification are recorded in hardware/motherboard/POWER.md.
    Input protection (new):
    - F1 PPTC 1.5 A hold / 3 A trip (1812L150/24MR) -> D2 SMBJ13A TVS -> Q1 AO3407A
    P-FET reverse-polarity, in that order so a surge or reversed jack crowbars
    through the fuse.
    - Q1 is drain-to-supply / source-to-load; source-to-supply passes reverse
    current through the body diode and fails silently.
    - AO3407A (Vgs +/-20 V) replaces AO3401A (+/-12 V), which sat at its absolute
    maximum on a 12 V rail and needed a gate zener conducting c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
    [motherboard.kicad_pcb, motherboard.kicad_sch]
2026-08-08 OPA2333 sense buffers and XTR200 EF fault-detection chain
    Two daughterboard revisions plus the firmware to drive them.
    OPA2333 sense buffers (root-causes the 3 mV offset):
    - The ~3 mV offset seen during the 8-board test was the AD7193's *internal*
    input buffer. With the 6:1 divider, a low-current channel's ADC input sits
    below the buffered mode's usable common-mode range, so the buffer added a
    systematic offset instead of tracking.
    - Fixed by disabling it (CONF.BUF = 0) and adding 8 external unity-gain
    followers: U13-U16 (OPA2333, 2 ch per package) between the divider taps and
    the ADC inputs, with R28-R35 1k series and C26-C33 100nF anti-alias
    (corner 1.59 kHz; was 339 kHz at 10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
    [daughterboard.kicad_pcb, daughterboard.kicad_sch, master_bom_lcsc.csv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]
2026-08-09 Refresh board renders; add pcb2blender render pipeline
    Both boards are routed, so the checked-in renders were stale. Regenerated
    every kicad-cli view from the current .kicad_pcb files:
    - motherboard.png now shows the reworked power front end (F1, D1/D2, Q1,
    K7805 U6, C5-C9) and the fully routed PCIe sockets / FFC connectors.
    - daughterboard*.png pick up the OPA2333 sense buffers U13-U16 with their
    R28-R35 / C26-C33 anti-alias networks, plus real component 3D models.
    - The motherboard now carries the same view set as the daughterboard:
    _top, _bottom and _top_transparent alongside the hero render.
    Also adds hardware/render/, a headless KiCad -> pcb2blender -> Cycles
    pipeline for photor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
    [motherboard.kicad_pcb]
2026-08-09 READMEs: matching image layout for both boards, incl. transparent view
    The motherboard README showed only its single hero render; it now carries the
    same block as the daughterboard — top/bottom table, 3D render, and the
    alpha-background top view, which was checked in but referenced nowhere.
    Also corrects the motherboard parts table, which still listed the removed PS1
    isolated DC-DC. Splits out a power-tree section matching the current
    schematic (F1/D2/Q1 protection chain, K7805 5 V switcher, LP5912 3V3 LDO,
    R7/R8 interlock) and points at POWER.md. master_bom.csv is still stale here
    and is flagged inline rather than silently trusted.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
2026-08-09 README: show both boards up front
    Adds a "The boards" section between the intro and the key numbers — the two
    top renders side by side, each linking through to that board's own README.
    The top view of the freshly routed motherboard and daughterboard both carry
    the current silicon (K7805 power front end; OPA2333 buffers U13-U16).
2026-08-09 BOM: add motherboard power stage, drop PS1, retotal
    The motherboard section still described the pre-rework board. Replaces the
    deleted PS1 (XP Power DSM2-12-S3-S, $10.37) with the twelve lines that
    actually populate the board now: F1/D2/Q1 protection chain, K7805-500R3
    switcher, LP5912-3.3 LDO, SS34 into Pico VSYS, the R7/R8 3V3_EN interlock,
    and the associated bulk capacitors. Also adds U2 (TMUX1208PW), corrects
    U1/U5 to SN74HC138PWR in TSSOP-16, and C1-C3 -> C1-C4.
    LCSC part numbers come from the schematic's own LCSC symbol field, so every
    line is quotable directly. Prices confirmed against those exact codes where
    they could be sourced (U6 C19188491 $0.4970, U4 C524780 $0.3409, F1 C142805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
    [master_bom.csv]
2026-08-10 motherboard: protected input stage, 12->5->3.3 V tree, 3V3_EN interlock
    Replaces PS1 with a staged supply and puts the Pico behind a hardware
    interlock, per hardware/motherboard/POWER.md.
    Input protection: F1 1812L150/24MR PPTC, D2 SMBJ13A TVS, Q1 AO3407A
    reverse-polarity P-FET (R1 100k gate). Q1 source now sources +12V, which
    previously reached J1-J8.A30 with no source at all.
    Rails: U6 K7805-500R3 (12->5 V) replaces the L7805, feeding D1 SS34 to
    the Pico VSYS and U4 LP5912-3.3 to the logic rail. Bulk and decoupling
    sized to datasheet minimums (C5/C7 on +12V, C6/C8 on +5V, C1-C4/C9 on
    +3.3V). D3/D4/D5 rail LEDs, J13 +12 V header.
    3V3_EN interlock: R8 4.7k from the board +3.3V rail to A1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
    [bom.csv, designators.csv, motherboard.kicad_pcb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]
2026-08-10 daughterboard: add silkscreen logos, refill zones
    Two LOGO footprints and the resulting zone refill. No netlist or
    component changes.
    [daughterboard.kicad_pcb]
2026-08-10 POWER.md: bring in line with the built board and the 9-15 V range
    The document was written as a forward-looking spec against the pre-rework
    netlist. Everything it called for landed in 397a4a4, so the status-bearing
    sections described a board that no longer exists.
    As-built: "What exists today" now shows the real tree, and the three
    defects it used to list are marked fixed. Added a refdes-drift table --
    the spec's U8/R3/C8-C11 are the board's U6/R1/C5,C6,C8,C9, and its
    "still to add" refdes (R4, R5, D4) collided with the rail LEDs.
    Input range: raised from 12 V nominal to 9-15 V, which changes three
    selections. D2 SMBJ13A conducts continuously above its 13 V standoff and
    must become SMBJ16A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
2026-08-12 hardware: release both boards to fabrication
    Fab outputs regenerated from the current designs and sent out 2026-08-12.
    Motherboard:
    - +12V sense divider R5/R10 (100k/22k) + C10 filter at the Pico ADC pin
    -> GPIO26/ADC0, ratio 0.1803
    - U3.~OE cut over from hardwired GND to GPIO19 (R9 10k pull-up)
    - D2 SMBJ13A -> SMBJ16A (13 V standoff conducts on a 15 V rail)
    - D6 gate-source clamp fixed at BZT52C18 (C192739)
    - J1..J8.B31 tied to GND on all eight; dangling one-node PRSNT net deleted
    Daughterboard:
    - 1k series resistors R28-R35 into the OPA2333 followers
    - L1 ferrite requoted C96708 (delisted) -> C133937, same 600R@100MHz
    - U10 REF5030IDGKR -> REF5030EIDR; test points and the card edge J1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
    [bom.csv, daughterboard.kicad_pcb, daughterboard.kicad_sch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]
2026-08-12 hardware: regenerate every derived file from the fab revision
    The fab outputs went out with the 2026-08-12 release, but the other
    generated artifacts still showed older boards. All re-exported from the
    current .kicad_sch/.kicad_pcb:
    - motherboard.net, Schematics/motherboard.pdf (were 2026-08-10 / 07-29)
    - Schematics/daughterboard.{net,pdf}, netlist_v2.net (were 07-29 / 07-27);
    the two daughterboard netlists are now the same export
    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
    [master_bom.csv]
2026-08-12 motherboard: restore Pico.wrl as A1's 3D model, re-render
    A1 pointed at the stock ${KICAD10_3DMODEL_DIR}/Module.3dshapes/
    RaspberryPi_Pico.step, which carries no textures, so the Pico rendered as a
    plain green slab with black blocks. Restored the textured
    ${KIPRJMOD}/Pico.wrl with its hand-tuned placement (offset 16/38.5/0,
    scale 2.5) from before the board rework, and re-rendered all four
    motherboard views: the Pico is back with its silkscreen artwork, RP2040,
    USB jack and castellations, correctly positioned.
    3D model references are viewer/render metadata only - gerbers, positions
    and the BOM are untouched, so this does not affect the boards at the fab.
    Edited in the .kicad_pcb directly ra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
    [motherboard.kicad_pcb]
2026-08-13 firmware: sync the bench tree (fw1.1 -> fw1.3)
    Replace the stale 2026-07-29 snapshot of firmware/motherboard-test with the
    working copy from ~/Documents/PlatformIO/Projects/mobo-test, which is the code
    actually running on the bench.
    Protocol grows the AD7193 sampling controls -- GAIN, CHOP, FILTER, REJ60,
    BIPOLAR, BUF and the ADC? readback -- plus DACINIT (recover a DAC that browned
    out back to its internal 2.5 V reference) and CALCLR. Adds the bench
    measurement suite driven from the GUI, the Keithley 2100 USBTMC driver, and the
    2026-07-23..07-30 campaign CSVs; loose CSVs move under tools/bench/<date>/.
    New docs/ covers the characterization procedure and the measure-path offset
    investigatio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
    [Rchar_ch0_20260617_201224.csv, Rchar_ch0_20260617_201413.csv, codes_ch0_20260730_164538.csv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]
2026-08-13 paper: take the bench tree's manuscript
    Replace paper/ with the copy from the mobo-test bench tree, which is ahead of
    this repo's Jul 29 snapshot. Section 8 gains the measured 2026-07-30 channel-0
    validation campaign -- a 64-point randomized sweep, 0.1-6.383 mA, against a
    996.4 ohm four-wire load read by a Keithley 2100:
    I_actual = 1.00319 * I_cmd + 2.43 uA
    i.e. +0.319 % gain error and I_OS = +2.43 uA (datasheet limit +-10 uA), with a
    0.070 uA rms linearity residual after removing gain and offset. Also documents
    the 44 mV low-signal knee in the sense path and the measured 0.46 s full
    64-channel scan, replacing the extrapolated 16-channel figure.
    Adds the five figures main.tex actually i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
2026-08-13 paper/todo.txt: restore the EF-chain and 2026-08-08 review notes
    The previous commit reverted todo.txt to the bench tree's copy, which dropped
    105 lines appended on 2026-08-08. That block was a strict superset -- the first
    343 lines were byte-identical -- so nothing else was at stake and it is
    re-appended verbatim here.
    It carries the EF-chain bench verification list (the two permutation tables in
    EFChain.cpp were never confirmed against hardware), the known limits of the
    shared EF flag, the reasoning against per-channel OD and hardware auto-shutdown,
    four hardware follow-ups (RSET tempco, the ambiguous XTR_OD default, VSP = 12 V
    thermal drift, missing EF pull-ups), and the resistance-self-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

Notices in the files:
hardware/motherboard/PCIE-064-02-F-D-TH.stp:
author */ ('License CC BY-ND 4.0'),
